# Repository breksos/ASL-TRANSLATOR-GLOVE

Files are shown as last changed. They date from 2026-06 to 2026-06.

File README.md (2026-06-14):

# ASL Sign Language Glove Translator

**GTU CSE496 Graduation Project** — Berk Hakan ÖGE & Utku GÖKÇEK, May–June 2026.

A wearable smart glove that recognises American Sign Language (ASL) gestures
and translates them into spoken text in real time. The user wears the glove,
performs a sign, and a Flutter mobile app speaks the translated word aloud
via TTS.

For the original project brief see [GLOVE_PROJECT.md](GLOVE_PROJECT.md).

---

## Repository layout

```
ASL/
├── README.md                ← you are here
├── GLOVE_PROJECT.md         original brief / spec
│
├── firmware/                ESP32 firmware (sender + receiver + diagnostics)
│   ├── arduino/             Arduino IDE .ino sketches (primary development path)
│   └── idf/                 ESP-IDF projects (parallel alternative; same logic)
│
├── hardware/
│   └── ASL_Glove/           KiCad PCB design for the prototype board
│
├── flutter_app/             Mobile app — BLE receive + TFLite inference + TTS
│
├── scripts/                 Python tooling
│   ├── record.py            primary data-recording UI
│   ├── strip_palm.py        create no-palm variant of dataset
│   └── diagnostics/         link-quality and sensor-health diagnostics
│       ├── sniff.py
│       ├── palm_check.py
│       ├── motion_check.py
│       ├── long_check.py
│       ├── long_csv_check.py
│       ├── soak_30min.py
│       └── inspect.py
│
├── data/                    labelled training samples (with palm channels)
├── data_nopalm/             same samples, palm stripped (45 channels)
│
└── docs/
    ├── datasheets/          part datasheets (MPU6050, ESP32-C3, etc.)
    └── images/              project photos, diagrams
```

---

## System architecture

```
┌─────────────────────────────────────────────────────────────────────┐
│                              The Glove                              │
│                                                                     │
│  ┌────────┐  ┌────────┐  ┌────────┐  ┌────────┐  ┌────────┐         │
│  │ thumb  │  │ index  │  │ middle │  │  ring  │  │ pinky  │         │
│  │ XIAO+  │  │ XIAO+  │  │ XIAO+  │  │ XIAO+  │  │ XIAO+  │         │
│  │ MPU6050│  │ MPU6050│  │ MPU6050│  │ MPU6050│  │ MPU6050│         │
│  └───┬────┘  └───┬────┘  └───┬────┘  └───┬────┘  └───┬────┘         │
│      │ ESP-NOW broadcast, channel 11, 50 Hz, dup-send               │
│      └────────────┬───────────┴───────────┴───────────┘             │
│                   ▼                                                 │
│         ┌────────────────────┐                                      │
│         │  ESP32 DevKit1     │                                      │
│         │  (back of wrist)   │                                      │
│         └─────┬──────────────┘                                      │
└───────────────┼─────────────────────────────────────────────────────┘
                │
                │  USB Serial (CSV) for recording sessions
                │  OR
                │  BLE GATT notify (45 floats × 50 Hz) for phone
                ▼
        ┌───────────────┐               ┌──────────────────────┐
        │   record.py   │               │   Flutter app        │
        │  (laptop)     │               │   (Android phone)    │
        │   → CSV files │               │   TFLite + TTS       │
        └───────┬───────┘               └──────────────────────┘
                ▼
        ┌──────────────────┐
        │  Edge Impulse    │
        │  CNN training    │
        │  → .tflite       │
        └──────────────────┘
                │
                └────────────► flutter_app/assets/models/
```

---

## Quick-start by role

### "I want to flash the firmware"

```sh
# Arduino — primary path
cd firmware/arduino
# Open the project you want in Arduino IDE 2.x (e.g. asl_finger_sender)
# Set FINGER_ID 1..5 per board, flash to each XIAO ESP32-C3
# Flash asl_hand_receiver to the DevKit1
```

Details: see [firmware/arduino/README.md](firmware/arduino/README.md).

For the IDF equivalent: see [firmware/idf/README.md](firmware/idf/README.md).

### "I want to record training data"

```sh
pip install pyserial
python scripts/record.py --port COM15 --label A
```

Press SPACE to record a sample, type a letter to change label, q to quit.
Saves `data/<label>/<label>_NNN.csv`. See `python scripts/record.py --help`.

### "I want to diagnose link health"

```sh
# Quick 20 s per-source rate + max gap
python scripts/diagnostics/palm_check.py

# 30 s while the user signs — checks for motion-induced loss
python scripts/diagnostics/motion_check.py

# 30 min passive soak — checks thermal/firmware stability
python scripts/diagnostics/soak_30min.py

# 5 min CSV-mode soak (asl_csv_logger firmware)
python scripts/diagnostics/long_csv_check.py
```

### "I want to train a model"

1. Record dataset to `data/<label>/*.csv` via `record.py`
2. (Optional) Strip palm channels: `python scripts/strip_palm.py` produces `data_nopalm/`
3. Upload to Edge Impulse with `edge-impulse-uploader --category split --label <X> data/<X>/*.csv` per class
4. Configure impulse: window 2000 ms, stride 500 ms, 50 Hz, **Raw Data**, **Classification (Keras)**
5. Normalize features: **scikit-learn StandardScaler**
6. Use the 1D CNN architecture (see `flutter_app/README.md` for the Keras code)
7. Train, evaluate on Model Testing tab
8. Deployment → TensorFlow Lite → download

### "I want to run the mobile app"

See [flutter_app/README.md](flutter_app/README.md) for full setup. The summary:

1. `cd flutter_app && flutter create --org com.gtu.aslglove --project-name asl_glove .`
2. Drop `asl-letters.tflite`, `asl-words.tflite` + labels into `assets/models/`
3. Drop normalization `stats.json` into `assets/normalization/`
4. `flutter run`

---

## Project status checklist

| Component | Status |
|---|---|
| Sender firmware (Arduino + IDF) | ✅ working, current |
| Receiver firmware (USB CSV path) | ✅ working |
| Receiver firmware (BLE bridge for phone) | ⏳ pending |
| Data recorder (`record.py`) | ✅ working |
| Diagnostic scripts | ✅ working |
| Smoke dataset (5 signs × 30) | ✅ collected |
| Smoke model (1D CNN, no-palm) | ✅ 87.7 % test accuracy |
| Letter dataset (A–Z × 60, multi-session) | ⏳ pending |
| Word dataset (15–20 signs × 60) | ⏳ pending |
| Flutter app skeleton | ✅ written, awaiting model file |
| Trie disambiguation engine | ⏳ pending |

---

## Key engineering decisions

- **Distributed ESP-NOW**, not a wired I2C mux — each finger XIAO transmits independently. Eliminates long wires across joints.
- **Channel 11**, not the default channel 6 — local 2.4 GHz neighbours saturate channel 6.
- **Duplicate-send on every sender** — each packet broadcast twice 800 µs apart. Receiver dedupes by `seq`. Roughly squares the loss rate.
- **External U.FL antennas** instead of the XIAO's PCB chip antenna — measured 10–15× link-loss improvement.
- **Palm MPU dropped** after A/B testing showed identical overall accuracy and *improved* NO class F1 without it. 45-channel input instead of 54.
- **1D CNN architecture**, not the default MLP — boosted test accuracy from 55 % to 88 % on fresh recordings.
- **Mobile-side ML** — ESP32 lacks compute for real-time CNN; phone runs the model.

---

## Open tasks (high-level)

Tracked in detail in the project's task list. Headline items:

1. Reassemble the glove with brick-pattern antenna layout + tight compression glove + clean power distribution
2. Multi-session data collection (4 sessions × 15 samples per sign)
3. Train production Letters and Words models
4. Add BLE GATT server to receiver firmware
5. Implement Trie engine for U/V, M/N, S/T disambiguation in letter mode

---

## License

Academic project, GTU CSE496. Use is permitted for educational reference;
contact authors for commercial use.

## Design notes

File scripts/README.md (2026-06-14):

# Python tooling

Two tiers:

| Tier | Purpose |
|---|---|
| `record.py`, `strip_palm.py` | Primary tools used during normal workflow |
| `diagnostics/*.py` | Link-quality + sensor-health monitors used when something seems off |

All scripts assume:
- Python 3.10+
- `pyserial` installed (`pip install pyserial`)
- Receiver is flashed with `asl_csv_logger` (CSV output, 921 600 baud)
- The repo's `data/` and `data_nopalm/` folders live at the project root

## Primary tools

### `record.py`

```sh
python scripts/record.py --port COM15 --label A
```

Interactive sample recorder. SPACE = record one 3-second window. Type a letter
+ Enter to change label. q = quit. Files land in `data/<label>/<label>_NNN.csv`.

Per-source staleness is checked at end of each window:
- Finger stale > 500 ms → prompt y/n
- Palm stale > 1500 ms → informational note, sample saved

### `strip_palm.py`

```sh
python scripts/strip_palm.py
```

Reads `data/<label>/*.csv` (55 columns: timestamp + 6 sources × 9 fields).
Writes `data_nopalm/<label>/*.csv` (46 columns: timestamp + 5 sources × 9
fields, palm channels removed).

Use after the A/B test verified palm doesn't help accuracy on your data.

## Diagnostics

All take 10-300 seconds; all open COM15 directly (DTR-resets the receiver on
open). Close Arduino Serial Monitor first or they'll fail with a permission
error.

### `diagnostics/sniff.py`

10-second raw capture; writes lines to `_sniff.log` in the project root.
General-purpose "what's actually coming out of the receiver right now".

### `diagnostics/palm_check.py`

20-second per-source health: packet rate, max inter-packet gap, % loss.
Used for "is the link clean right now?"

### `diagnostics/motion_check.py`

30 s test where you wear the glove and perform signs. Reports max gap per
source. Distinguishes static-pose link quality vs motion-induced loss.

### `diagnostics/long_check.py`

5-minute soak using the live-PRY receiver firmware (not CSV).

### `diagnostics/long_csv_check.py`

5-minute soak using the CSV-logger receiver firmware. Per-30-second bucket
packet counts per source. Used to confirm palm survival across a long session.

### `diagnostics/soak_30min.py`

30-minute passive soak (glove on desk, not worn). Identifies thermal /
firmware-state failures distinct from motion-induced RF issues.

### `diagnostics/inspect.py`

```sh
python scripts/diagnostics/inspect.py path/to/data/A
```

Sanity-checks every CSV in a label folder: row count, NaN, all-zero detection,
intra-sample std, across-sample drift. Run after a recording session before
uploading to Edge Impulse.

## Conventions

- All output files (CSVs, logs) go to the project root or `data/` — never to
  `scripts/`.
- COM port is hardcoded to **COM15** in many diagnostics; edit the file or
  pass `--port` where supported.
- No path is relative — they use absolute paths anchored at
  `C:\Users\ASUS\Desktop\Projeler\ASL`. If you move the repo, update them.

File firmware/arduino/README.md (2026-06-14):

# Arduino firmware

Primary firmware tree. Open each project in Arduino IDE 2.x; each subfolder
is one `.ino` sketch that compiles to one board.

## Projects

| Sketch | Target board | Role |
|---|---|---|
| `asl_finger_sender/` | XIAO ESP32-C3 | One per finger. Set `FINGER_ID` 1..5 before flashing each board. |
| `asl_hand_receiver/` | ESP32 DevKit v1 | Receives all 5 fingers via ESP-NOW + local palm IMU. Emits CSV over USB. |
| `asl_csv_logger/` | ESP32 DevKit v1 | Variant of the receiver — pure CSV output at 921 600 baud, no live PRY prints. Used with `scripts/record.py`. |
| `pinky_test/` | XIAO ESP32-C3 | Sender variant that prints diagnostics over USB while still broadcasting. Use to isolate which board is dropping packets. |
| `i2c_scan/` | XIAO ESP32-C3 | Confirms MPU6050 is wired correctly on each finger. |
| `print_mac/` | XIAO ESP32-C3 | Prints the board's STA MAC. Label your boards. |
| `hello_test/` | XIAO ESP32-C3 | Minimal blink/heartbeat sanity check. |

## Flash workflow

1. **Per finger** (5 times, FINGER_ID 1..5):
   - Open `asl_finger_sender/asl_finger_sender.ino`
   - Edit `#define FINGER_ID` near the top to the finger you're flashing
   - Tools → Board → "XIAO_ESP32C3"; Port: pick the right COM
   - Upload, watch the boot log: `[Finger N] starting…`
2. **Receiver**:
   - Open `asl_hand_receiver/asl_hand_receiver.ino` (for normal live use)
   - OR `asl_csv_logger/asl_csv_logger.ino` (for recording sessions)
   - Tools → Board → "ESP32 Dev Module"
   - Upload, open Serial Monitor at **921 600 baud**

## Build settings

| Setting | Value |
|---|---|
| Board family | Arduino-ESP32 core 3.x (Espressif via Boards Manager) |
| Sender CPU freq | default (160 MHz) |
| Receiver CPU freq | default (240 MHz) |
| Partition scheme | default |

## Hardware assumptions (latest)

- ESP-NOW channel: **11** (not the default 6 — channel 6 is RF-congested in the lab)
- Senders broadcast in dup-send mode (each packet twice with 800 µs gap)
- Phase stagger: 4 ms × (FINGER_ID − 1)
- I2C: SDA = GPIO 6, SCL = GPIO 7 on XIAO; SDA = GPIO 21, SCL = GPIO 22 on DevKit1
- Receiver palm: optional (removed in current production design, code still supports it)
- All boards run on a shared 5 V rail from a 5 A bench adapter
- DevKit1 receiver: mounted on back of wrist, antenna end (meander trace) pointing toward fingertips

## Related Python tooling

| Tool | What |
|---|---|
| `scripts/record.py` | Drives `asl_csv_logger` over USB, captures labelled samples |
| `scripts/diagnostics/*` | Link-quality + sensor-health monitors that consume the receiver's USB output |

## See also

- `firmware/idf/README.md` for the ESP-IDF equivalent
- Top-level `README.md` for the system architecture overview

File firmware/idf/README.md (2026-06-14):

# ASL Glove — ESP-IDF version

Ported from the Arduino `.ino` sketches in `ASL_Latest_Ver/` and rewritten with
every fix from the precision/noise review. One PlatformIO-style project per
firmware image; shared MPU6050 + Kalman code lives in `components/glove_common`.

## Requirements

- **ESP-IDF v5.4 or newer** (uses the new `i2c_master` driver and the
  `wifi_tx_info_t` ESP-NOW send-callback signature).
- Python 3.8+, the `esptool`/`idf.py` toolchain (installed by ESP-IDF).
- VS Code with the official **Espressif IDF** extension is the easiest way to
  build/flash from a GUI; everything also works from the IDF shell.

## Projects

| Folder | Target | Role |
|---|---|---|
| `asl_finger_sender` | esp32c3 | One image per finger XIAO. Edit `FINGER_ID` (1..5) in `main/main.c` before each flash. |
| `asl_hand_receiver` | esp32 | DevKit1 on back of hand. Reads palm IMU locally + receives fingers over ESP-NOW. Live PRY @ 5 Hz, stats @ 1 Hz. |
| `asl_csv_logger` | esp32 | Same wiring as receiver, but emits one CSV row per packet on UART @ 921600 baud. Use for data-loss analysis. |
| `pinky_test` | esp32c3 | Pinky XIAO with extra USB diagnostics every 5 s (I2C ok/fail, max consecutive failure burst, send ok/fail). Behaves as `FINGER_ID=5` for the rest of the glove. |
| `i2c_scan` | esp32c3 | Probes every 7-bit I2C address — sanity check the MPU6050 wiring on a XIAO. |
| `print_mac` | esp32c3 | Prints STA MAC, used to label modules. |

## Build / flash workflow

From the IDF shell (or VS Code → "ESP-IDF: Open ESP-IDF Terminal"):

```sh
cd IDF_Ver/asl_finger_sender
idf.py set-target esp32c3           # only first time, or after changing target
idf.py build
idf.py -p COM7 flash monitor        # adjust COM port
```

Stop the monitor with `Ctrl+]`.

The receiver and CSV logger use `esp32` target:
```sh
cd IDF_Ver/asl_hand_receiver
idf.py set-target esp32
idf.py build
idf.py -p COM15 flash monitor
```

### Per-finger flashing
`FINGER_ID` is a `#define` in `asl_finger_sender/main/main.c`. Change it,
rebuild, flash. Recommended workflow: tape a label with the finger name on
each XIAO before mounting, and keep a list of which MAC → finger so you can
re-flash later without confusion (`print_mac` helps here).

### ESP-NOW channel
All boards must agree on `ESPNOW_CHANNEL` — defined in `asl_finger_sender`,
`pinky_test`, `asl_hand_receiver`, `asl_csv_logger`. Default is 6. If your
home Wi-Fi router is on channel 6 you will see packet loss in the receiver
`[stats]` output; change to 1 or 11 on every board.

## What the optimised firmware does differently

The review went through each issue; this is a compressed map from "fix" to
"where it lives" so you can audit the code.

| Fix from review | Implementation |
|---|---|
| Accel-magnitude gating in Kalman | `if (dev_g < ACCEL_GATE_MS2) kalman_update(...) else kalman_predict(...)` in every sampling loop |
| DLPF 10 Hz (was 21 Hz) | `wreg(m, REG_CONFIG, 0x05)` in [mpu6050.c](components/glove_common/mpu6050.c) |
| I2C @ 400 kHz (was 100 kHz) | `scl_speed_hz = 400000` in `mpu6050.c::open_bus` |
| Deadline scheduler (was `delay(20)`) | `next_us += PERIOD_US; spin until esp_timer_get_time() >= next_us` |
| `dt` fallback fixed | `dt = SEND_PERIOD_US / 1e6f` (was a wrong 0.01s default) |
| Calibration stillness check | `mpu6050_calibrate_still()` computes gyro variance and rejects if it exceeds 4 dps² |
| Average raw accel, not angles | `mpu6050_calibrate_still()` sums `ax,ay,az` then calls `atan2` once |
| Online gyro-bias EMA when still | `cal.gx_bias += BIAS_EMA_ALPHA * (g[0] - cal.gx_bias)` in every loop |
| Yaw reset on sustained stillness | `if (still_since > 0 && (now - still_since) > STILL_RESET_US) yaw = 0` — replaces the old `yaw *= 0.99` |
| Serial @ 921 600 on receivers | `CONFIG_ESP_CONSOLE_UART_BAUDRATE=921600` in `sdkconfig.defaults` |
| Receiver live print slowed to 5 Hz | `last_print > 200 ms` in `asl_hand_receiver` |
| Palm IMU in its own FreeRTOS task | `xTaskCreate(palm_task, ...)` in receiver / CSV logger |
| CSV emit out of ESP-NOW callback | `xQueueSend` from `recv_cb`, `emitter_task` drains and prints |
| Reset-tolerant loss counter | `else if (p.seq < s->seq) { s->lost_count = 0; }` in receiver `recv_cb` |
| TX failure counter on all senders | `s_tx_ok / s_tx_fail_cb / s_tx_fail_imm` in every sender |
| I2C bus recovery | `mpu6050_recover_bus()` — bit-bangs SCL 9 times and reinits the bus |

## Repository layout
```
IDF_Ver/
├── README.md                       ← this file
├── components/
│   └── glove_common/
│       ├── CMakeLists.txt
│       ├── include/
│       │   ├── kalman.h
│       │   ├── mpu6050.h
│       │   └── packet.h
│       ├── kalman.c
│       └── mpu6050.c
├── asl_finger_sender/  …
├── asl_hand_receiver/  …
├── asl_csv_logger/     …
├── pinky_test/         …
├── i2c_scan/           …
└── print_mac/          …
```

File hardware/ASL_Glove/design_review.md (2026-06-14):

# ASL Glove Design Review

**Project:** ASL_Glove (KiCad 9, single sheet, 2-layer PCB)
**Date:** 2026-04-03
**Analyzers:** analyze_schematic.py, analyze_pcb.py (--full), analyze_emc.py
**Datasheets:** MPU-6050.pdf (104KB, InvenSense), ESP32-C3_datasheet.pdf (875KB, Espressif)

---

## Critical Findings

| Severity | Issue | Section |
|---|---|---|
| WARNING | CPOUT (MPU-6050 pin 20) has no decoupling capacitor — IMU may not function | Signal Analysis |
| WARNING | GND copper pour zone is defined but NOT filled — no ground plane on board | PCB Layout |
| WARNING | Power traces (+3V3, GND) use 0.2mm width — marginal for ESP32-C3 peak Wi-Fi current | PCB Layout |
| WARNING | No MPNs on any component (0% MPN coverage) — board cannot be ordered without manual lookup | Component Summary |
| SUGGESTION | All signal nets are unnamed — I2C, UART, and config signals have auto-generated names | Schematic Quality |
| SUGGESTION | Missing bulk cap (10µF) near MPU-6050 VDD — datasheet recommends 100nF + 10µF | Signal Analysis |

---

## Component Summary

| Type | Count | References |
|---|---|---|
| IC / Module | 2 | U1 (ESP32-C3-DevKitM-1), U2 (MPU-6050) |
| Capacitor | 4 | C1–C4 |
| Resistor | 3 | R1–R3 |
| Connector | 1 | J1 (Conn_01x02) |
| Jumper | 1 | JP1 (ROLE_SEL) |
| Test point | 4 | TP1–TP4 (TX, RX, GND, 3V3) |
| **Total** | **15** | |

**Nets:** 36 schematic / 37 PCB | **No-connects:** 18 | **Power rails:** +3V3, GND

**Sourcing audit:** 0/10 components have MPNs. All parts require manual MPN assignment before ordering or JLCPCB assembly.

---

## Power Tree

```
J1 (external 3.3V supply)
  └── +3V3 rail ─── U1 3V3 pin (bidirectional — also sources from USB LDO on DevKitM-1)
                ├── U2 VDD (pin 13)
                ├── U2 VLOGIC (pin 8)
                ├── C1 100nF (bulk decoupling)
                ├── C2 10µF  (bulk decoupling)
                ├── C3 100nF (MPU-6050 VDD decoupling)
                ├── C4 100nF (MPU-6050 VDD decoupling)
                ├── R1 4.7kΩ (I2C SDA pull-up)
                ├── R2 4.7kΩ (I2C SCL pull-up)
                └── R3 10kΩ  (JP1 ROLE_SEL pull-up)
```

**Note:** The ESP32-C3-DevKitM-1 module has its own onboard 3.3V LDO from USB VBUS. When the board is powered via USB, U1's 3V3 pins source +3V3. When powered externally via J1, J1 drives the +3V3 rail. Both paths connect to the same rail — avoid powering both simultaneously unless a diode-OR circuit is used.

---

## Analyzer Verification

### Component Count
Schematic: 15 components (excluding power symbols) — PCB: 15 footprints. **Match ✓**

### Component Pinout Verification

| Ref | Value | Datasheet Verified | Key Connections | Status |
|-----|---|---|---|---|
| U1 | ESP32-C3-DevKitM-1 | Unverified (PDF unavailable — web page URL only) | GND(1), 3V3(2,3), IO10(11), IO8/SDA(25), IO9/SCL(26), RX(28), TX(29) | Plausible — standard DevKitM-1 pinout |
| U2 | MPU-6050 | Unverified (pdftoppm unavailable) | VDD(13)=3V3, VLOGIC(8)=3V3, GND(18), AD0(9)=GND, FSYNC(11)=GND, SCL(23), SDA(24) | Plausible — matches standard MPU-6050 symbol |
| R1 | 4.7kΩ | Skipped (2-pin passive) | Pin1=3V3, Pin2=SDA | ✓ |
| R2 | 4.7kΩ | Skipped (2-pin passive) | Pin1=3V3, Pin2=SCL | ✓ |
| R3 | 10kΩ | Skipped (2-pin passive) | Pin1=3V3, Pin2=JP1/IO10 | ✓ |
| C1–C4 | 100nF/10µF | Skipped (2-pin passive) | +3V3/GND | ✓ |
| J1 | Conn_01x02 | Skipped | Pin1=+3V3, Pin2=GND | ✓ |
| JP1 | ROLE_SEL | Skipped | Pin1=IO10 via R3, Pin2=GND | ✓ |

**Verification gap:** pdftoppm is not available in this environment, so datasheet PDFs could not be read directly. The MPU-6050 pinout is based on well-known community knowledge of this part (extremely common, stable for 15+ years). U1 pinout is based on the KiCad symbol for the DevKitM-1 dev board module. Both are assessed as **plausible** — but formal datasheet verification is recommended before ordering.

### Connector Pin Tables

**J1 (Power input):**
| Pin | Net | Function |
|-----|-----|---|
| 1 | +3V3 | 3.3V supply input |
| 2 | GND | Ground |

**JP1 (ROLE_SEL jumper):**
| Pin | Net | Function |
|-----|-----|---|
| 1 | IO10 (via R3 10kΩ to +3V3) | Role select signal — HIGH when open, LOW when shorted to GND |
| 2 | GND | Ground |

**Test points:**
| Ref | Net | Label |
|-----|-----|---|
| TP1 | U1.TX | UART TX |
| TP2 | U1.RX | UART RX |
| TP3 | GND | Ground |
| TP4 | +3V3 | 3.3V supply |

### Net Tracing

**+3V3 power rail:** J1.1 → U1.2/3 → U2.VDD(13) → U2.VLOGIC(8) → C1/C2/C3/C4 → R1.1 → R2.1 → R3.1 → TP4. Continuous, no gaps. ✓

**GND:** J1.2 → U1.GND(1,6,8,12,15,16,19,24,27,30) → U2.GND(18) → U2.AD0(9) → U2.FSYNC(11) → C1/C2/C3/C4 → JP1.2 → TP3. Continuous. ✓

**I2C SDA:** R1.2 → U2.SDA(24) → U1.IO8(25). ✓

**I2C SCL:** R2.2 → U2.SCL(23) → U1.IO9(26). ✓

**UART TX:** U1.TX(29) → TP1. ✓

**UART RX:** U1.RX(28) → TP2. ✓

**ROLE_SEL:** +3V3 → R3(10kΩ) → U1.IO10(11) → JP1.1 (and JP1.2=GND). When JP1 open: IO10 pulled HIGH. When shorted: IO10 pulled LOW. ✓

### PCB Verification

- Footprint count: 15 schematic = 15 PCB ✓
- Board dimensions: 32.0 × 34.0mm
- Routing: complete (0 unrouted nets)
- Vias: **0** (no vias at all)

---

## Signal Analysis Review

### I2C Bus

Detected correctly: ESP32-C3 (master) ↔ MPU-6050 (slave, AD0=GND → address 0x68).

| Parameter | Value | Assessment |
|---|---|---|
| SDA pull-up | R1 = 4.7kΩ to +3V3 | ✓ Standard — appropriate for 100/400kHz I2C |
| SCL pull-up | R2 = 4.7kΩ to +3V3 | ✓ Standard |
| Bus capacitance (estimated) | ~10pF | Low (2 devices, short traces) — rise time well within spec |
| I2C address | 0x68 (AD0=GND) | ✓ |

**I2C GPIO assignment:** IO8 (SDA) and IO9 (SCL). On ESP32-C3, I2C can be mapped to any GPIO via the `i2c_param_config()` driver call. Both GPIO8 and GPIO9 are valid for I2C — no issues.

### MPU-6050 Application Circuit

The MPU-6050 requires specific external components beyond VDD/GND decoupling:

| Requirement | Schematic | Status |
|---|---|---|
| VDD decoupling 100nF | C3 or C4 (100nF, ~5mm) | ✓ Present |
| VDD bulk cap 10µF | Not present | **WARNING** — datasheet recommends 100nF + 10µF |
| VLOGIC decoupling 100nF | C3/C4 shared rail | Acceptable (VLOGIC=VDD=3.3V here) |
| CPOUT cap 2.2nF to GND | **Not present** | **WARNING — required for internal charge pump** |
| REGOUT cap 100nF | NC (pin 20 floats) | **WARNING** — floated; should have cap to GND |

The CPOUT / REGOUT omission is the highest-risk issue in this design. Without the charge pump capacitor, the MPU-6050's internal oscillator may not start reliably, resulting in no IMU data.

### Decoupling Coverage

| IC | Closest Cap | Distance | Assessment |
|----|---|---|---|
| U1 (ESP32-C3-DevKitM-1) | C1 (100nF) + C2 (10µF) | 9.06mm | Module has onboard decoupling — external caps serve as rail bulk supply. Acceptable for a dev board module. |
| U2 (MPU-6050) | C4 (100nF) | 4.94mm | Borderline — under 5mm is acceptable but closer is better. Missing 10µF bulk. |

### Protection Devices

No ESD or TVS protection on any connector. J1 (power input) and JP1 (external header) are exposed interfaces with no protection. For a glove device that will be plugged/unplugged in the field, TVS protection on J1 is recommended.

---

## PCB Layout Review

### Ground Plane — CRITICAL GAP

The GND zone is **defined** in the PCB but **not filled** (`is_filled: false`). There is no copper pour on either layer for GND. This has significant consequences:

1. **EMC**: Return currents take longer paths through traces instead of a solid plane — increases radiated emissions
2. **Signal integrity**: I2C and UART signals lack controlled return paths
3. **Noise**: MPU-6050 is sensitive to power supply noise; a ground plane significantly reduces it

**Fix:** In KiCad, press `B` (Edit → Fill All Zones) before generating Gerbers. The zone outline is already drawn.

### Power Trace Width

| Net | Current trace width | Est. peak current | IPC-2221 minimum (1oz, external) | Status |
|-----|---|---|---|---|
| +3V3 | 0.2mm | ~150mA (ESP32 Wi-Fi peak) | ~0.3mm for 150mA, 10°C rise | Marginal |
| GND | 0.2mm | ~150mA | ~0.3mm | Marginal |

The ESP32-C3 module draws up to ~150mA peak during Wi-Fi TX bursts. The current 0.2mm traces are at the minimum DRC rule limit and within acceptable range for average current (the module's onboard LDO handles instantaneous peaks), but widening to 0.5mm would reduce voltage droop and improve reliability.

### Via Stitching

**0 vias on the entire board.** Since all components are on F.Cu and there's no B.Cu routing, vias are not needed for signal routing. However, ground stitching vias connecting the GND zone (once filled) to a B.Cu GND pour would significantly improve EMC. See EMC findings.

### Placement

| Issue | Detail |
|---|---|
| J1 edge clearance | 0.7mm — passes DRC (0.5mm minimum), but tight for a connector |
| Component density | 1.4 components/cm² — moderate density, no courtyard overlaps |
| All components front side | ✓ — simplifies assembly |

### DFM (JLCPCB Standard Tier)

| Metric | Value | Limit | Status |
|---|---|---|---|
| Min track width | 0.2mm | 0.127mm | ✓ |
| Min spacing | 0.3mm | 0.127mm | ✓ |
| Board size | 32×34mm | Up to 500×500mm | ✓ |
| DRC violations | 0 | 0 | ✓ |

---

## EMC Summary (from analyze_emc.py)

**Score: 87/100** — see `emc_analysis.json` for full findings. Key items:

| Severity | Rule | Finding |
|---|---|---|
| HIGH | DC-001 | Decoupling caps 9.1mm from U1 — acceptable for module, monitor if noise issues |
| MEDIUM | VS-001 | No ground stitching vias |
| LOW | IO-001 | No filtering on J1 or JP1 connectors |
| INFO | EE-001 | Board resonance at 2102/2233 MHz — near 2.4GHz Wi-Fi band |

---

## Issues Found — Prioritized

| Priority | Severity | Issue | Fix |
|---|---|---|-----|
| 1 | WARNING | MPU-6050 CPOUT/REGOUT has no capacitor — IMU may not work | Add 2.2nF to CPOUT (pin 20) and 100nF to REGOUT (pin 10), both to GND |
| 2 | WARNING | GND copper pour not filled | Press `B` in KiCad PCB editor before exporting Gerbers |
| 3 | WARNING | Power traces only 0.2mm | Widen +3V3 and GND traces to 0.5mm |
| 4 | WARNING | 0% MPN coverage | Add MPN properties to all components; especially U1, U2 |
| 5 | SUGGESTION | Missing bulk cap near MPU-6050 | Add 10µF capacitor near U2 VDD |
| 6 | SUGGESTION | All signal nets unnamed | Add net labels: SDA, SCL, TX, RX, ROLE_SEL |
| 7 | SUGGESTION | No ESD protection on J1 | Add TVS (e.g., PRTR5V0U2X) on J1 power pins |
| 8 | SUGGESTION | GND PWR_FLAG missing | Add PWR_FLAG to GND net to suppress ERC warning |
| 9 | SUGGESTION | No ground stitching vias | Add stitching vias around board edges after filling GND zone |

---

## Positive Findings

- Routing is complete — no unrouted nets
- I2C pull-up values (4.7kΩ) are correct for 3.3V bus at 100/400kHz
- MPU-6050 I2C address (AD0=GND → 0x68) is explicitly set
- FSYNC tied to GND — correct for standalone IMU operation
- Test points provided for UART TX/RX, GND, and 3V3 — good for debug
- DFM passes JLCPCB standard tier — manufacturable as-is
- ROLE_SEL jumper has proper pull-up — clean logic level configuration

---

## Generated Files

| File | Purpose | Regenerable |
|---|---|---|
| `schematic_analysis.json` | Schematic analyzer output | Yes |
| `pcb_analysis.json` | PCB analyzer output (--full) | Yes |
| `emc_analysis.json` | EMC pre-compliance analysis | Yes |
| `datasheets/MPU-6050.pdf` | InvenSense MPU-6050 datasheet | Yes |
| `datasheets/ESP32-C3_datasheet.pdf` | Espressif ESP32-C3 datasheet | Yes |
| `datasheets/index.json` | Datasheet manifest | Yes |
| `design_review.md` | This report | Yes |

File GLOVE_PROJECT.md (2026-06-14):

# ASL Sign Language Glove Translator — Project Brief
**GTU CSE496 Graduation Project | Berk Hakan ÖGE & Utku GÖKÇEK**

---

## What This Project Does
A wearable smart glove that recognizes American Sign Language (ASL) gestures and translates them into spoken text in real time. The user wears the glove, performs a sign, and a companion Flutter mobile app speaks the translated word aloud via TTS.

**Two-layer recognition:**
1. **Word-level gestures** — ~30–50 common ASL signs (hello, yes, no, help, water, etc.) using dynamic IMU motion over time
2. **Fingerspelling fallback** — A–Z static letters for names and unknown words, with context-aware disambiguation (trie-based word completion) for ambiguous letter pairs (U/V, M/N, S/T)

---

## Hardware (All Parts In Hand)

### On the Glove
| Component | Qty | Role |
|---|---|---|
| ESP32 DevKit V1 | 1 | Main MCU — reads all sensors, streams raw data over BLE |
| MPU6050 GY-521 | 6 | 6-axis IMU — 5 on fingers (one per finger) + 1 on back of hand for wrist/global orientation |
| TCA9548A I2C Multiplexer | 1 | Lets all 6 MPU6050s (same I2C address 0x68) coexist on one ESP32 I2C bus |
| Flex Sensor 2.2" | 5 | Analog bend detection per finger — supplements IMU data for stronger dataset |
| CD4051 Analog Multiplexer | 1 | Routes all 5 flex sensor ADC signals into single ESP32 ADC pin |
| Li-Po 3.7V 1000mAh | 1 | Power source |
| TP4056 USB-C charger | 1 | Safe Li-Po charging |

### Mobile
| Component | Role |
|---|---|
| Flutter App (Android/iOS) | BLE receive → ML classification → text buffer → TTS output |

---

## Architecture

```
[Glove Hardware]
  5x Flex Sensors
       │
    CD4051 (analog mux)
       │ (1 ADC pin)
       ▼
  ESP32 DevKit V1  ◄──── 6x MPU6050
       │                     │
       │              TCA9548A (I2C mux)
       │              GPIO21=SDA, GPIO22=SCL
       │
    [BLE]
       │
       ▼
  Flutter Mobile App
       │
   ┌───┴────────────┐
   │  ML Model      │  ← 1D CNN (TFLite) trained via Edge Impulse
   │  Text Buffer   │  ← accumulates letters/words
   │  Trie Engine   │  ← context disambiguation for ambiguous letters
   │  TTS Output    │  ← flutter_tts
   └────────────────┘
```

**Key architectural decisions:**
- ML runs on **mobile, not ESP32** — ESP32 is too weak for real-time model inference
- ESP32 only streams **raw sensor data** over BLE — no classification on device
- TCA9548A eliminates need for a second ESP32 — single board handles all 6 IMUs
- CD4051 is on a **separate analog bus** from TCA9548A — no conflict

---

## ESP32 Pin Mapping

| Pin | Function |
|---|---|
| GPIO21 | I2C SDA → TCA9548A |
| GPIO22 | I2C SCL → TCA9548A |
| GPIO34 (ADC) | CD4051 output (flex sensors) |
| GPIO25 | CD4051 select pin A |
| GPIO26 | CD4051 select pin B |
| GPIO27 | CD4051 select pin C |
| Built-in radio | BLE (no extra pins needed) |

**TCA9548A channels:**
- Channel 0 → MPU6050 (thumb)
- Channel 1 → MPU6050 (index finger)
- Channel 2 → MPU6050 (middle finger)
- Channel 3 → MPU6050 (ring finger)
- Channel 4 → MPU6050 (pinky finger)
- Channel 5 → MPU6050 (back of hand / wrist)
- Channels 6–7 → spare

**CD4051 channels:**
- Channel 0 → Flex sensor (thumb)
- Channel 1 → Flex sensor (index)
- Channel 2 → Flex sensor (middle)
- Channel 3 → Flex sensor (ring)
- Channel 4 → Flex sensor (pinky)

---

## Sensor Data Format

Each sample is a time window of raw readings streamed from ESP32 to mobile over BLE.

**Per timestamp (at 50Hz):**
```
imu[0..5]: { accelX, accelY, accelZ, gyroX, gyroY, gyroZ }  // 6 IMUs × 6 values = 36
flex[0..4]: { raw_adc }                                        // 5 flex values
─────────────────────────────────────────────────────────────
Total per sample: 41 values
At 50Hz over 1s window: 50 × 41 = 2050 values per gesture
```

BLE packet: send as packed float array or JSON — keep under BLE MTU (512 bytes typical). Consider sending at 50Hz as continuous stream and letting mobile handle windowing.

---

## ML Pipeline

### Phase 1 — DTW Baseline (build first, fast to implement)
- Record 1 template per gesture
- At runtime compare live window to all templates using DTW distance
- Classify as closest match
- No training needed — add new gesture by recording one sample
- Use this to validate the full hardware → mobile pipeline works

### Phase 2 — 1D CNN via Edge Impulse (final model)
- Collect 50–100 samples per gesture in Edge Impulse data collector
- Input: time-series window (50 samples × 41 channels)
- Architecture: 1D Conv → Pool → 1D Conv → Pool → Dense → Softmax
- Export as TFLite → integrate into Flutter via `tflite_flutter` package
- Target accuracy: ≥85% letters, ≥90% words

### Gesture vocabulary plan
- **Static letters:** A–Z (fingerspelling)
- **Word gestures (dynamic):** ~30–50 common signs — hello, yes, no, help, water, food, please, sorry, good, bad, I, you, want, need, more, stop, go, thank you, where, what, name, again, understand, know, not, like, want, hurt, sick, call
- **Control gestures:** space (closed fist hold), backspace, switch mode (fingerspell ↔ word)

---

## Flutter App Structure

```
lib/
├── main.dart
├── ble/
│   ├── ble_manager.dart          # flutter_blue_plus — scan, connect, subscribe
│   └── sensor_packet.dart        # parse raw BLE bytes into SensorFrame struct
├── ml/
│   ├── classifier.dart           # load TFLite model, run inference on window
│   ├── dtw_classifier.dart       # DTW baseline (Phase 1)
│   └── gesture_window.dart       # sliding window buffer (1s at 50Hz)
├── text/
│   ├── text_buffer.dart          # accumulate letters → words → sentences
│   ├── trie_engine.dart          # context disambiguation for ambiguous letters
│   └── word_completer.dart       # suggests completions from trie
├── tts/
│   └── tts_manager.dart          # flutter_tts wrapper
└── ui/
    ├── home_screen.dart           # main display — current word, sentence, mode
    └── settings_screen.dart       # BLE device picker, model settings
```

**Flutter dependencies to add:**
```yaml
dependencies:
  flutter_blue_plus: ^1.31.0
  tflite_flutter: ^0.10.4
  flutter_tts: ^3.8.5
  permission_handler: ^11.0.0
```

---

## ESP32 Firmware Structure

```
firmware/
├── src/
│   └── main.cpp
├── lib/
│   ├── TCA9548A/
│   │   └── mux.h              # selectChannel(uint8_t ch), readMPU(uint8_t ch)
│   ├── MPU6050/
│   │   └── imu.h              # initIMU(), readIMU() → struct IMUData
│   ├── FlexSensors/
│   │   └── flex.h             # selectFlex(uint8_t ch), readFlex() → int
│   └── BLE/
│       └── ble_stream.h       # init BLE, sendPacket(float* data, int len)
└── platformio.ini
```

**Key firmware logic:**
```cpp
// Main loop at 50Hz
void loop() {
  for (int ch = 0; ch < 6; ch++) {
    selectMPU(ch);           // TCA9548A switch
    readMPU6050(ch);         // fill imu_data[ch]
  }
  for (int ch = 0; ch < 5; ch++) {
    selectFlex(ch);          // CD4051 switch
    flex_data[ch] = analogRead(ADC_PIN);
  }
  packAndSend();             // BLE notify
  delay(20);                 // 50Hz
}
```

---

## Build Order (Phase by Phase)

### Phase 1 — Hardware Validation (do first)
1. Wire TCA9548A to ESP32 (SDA/SCL)
2. Connect one MPU6050 to TCA9548A channel 0, verify I2C reads
3. Add remaining 5 MPU6050s one at a time, verify each channel
4. Wire CD4051 to ESP32 ADC pin
5. Connect flex sensors through CD4051, verify analog reads
6. Confirm all 11 sensors reading simultaneously at 50Hz via Serial Monitor

### Phase 2 — BLE Streaming
1. Add BLE GATT server to firmware
2. Pack sensor frame as byte array, send via BLE notify characteristic
3. Build minimal Flutter app that connects and prints received packets to console
4. Verify data integrity and latency end-to-end

### Phase 3 — DTW Baseline Classifier
1. Add data logging mode to firmware (dump to Serial as CSV)
2. Record 5–10 gesture templates per sign
3. Implement DTW in Flutter/Dart
4. Test full pipeline: gesture → BLE → classify → display text

### Phase 4 — Dataset Collection + Edge Impulse
1. Set up Edge Impulse project with 41-channel time-series input
2. Collect 50–100 samples per gesture class
3. Train 1D CNN, validate accuracy
4. Export TFLite model
5. Integrate into Flutter via tflite_flutter

### Phase 5 — App Polish
1. Text buffer + trie disambiguation engine
2. TTS output via flutter_tts
3. Word/letter mode switching
4. UI for sentence display

---

## Success Criteria (for TA)
1. Static letter recognition accuracy ≥ 85% across A–Z
2. Word-level gesture accuracy ≥ 90% for defined 30-word vocabulary
3. End-to-end latency (gesture → audio) ≤ 1 second
4. BLE connection stable within 5 seconds of app launch
5. Battery life ≥ 3 hours continuous use

---

## Key Libraries & Tools
| Tool | Purpose |
|---|---|
| PlatformIO | ESP32 firmware development |
| Wire.h | I2C communication (Arduino) |
| MPU6050.h | IMU driver |
| BLEDevice.h | ESP32 BLE server |
| Edge Impulse | Dataset collection + 1D CNN training |
| flutter_blue_plus | BLE client in Flutter |
| tflite_flutter | Run TFLite model in Flutter |
| flutter_tts | Text-to-speech output |

---

## Notes for Claude Code
- Start with Phase 1 hardware validation firmware — get all sensors reading before writing any ML code
- Use PlatformIO, not Arduino IDE — better dependency management
- ESP32 I2C default pins: SDA=GPIO21, SCL=GPIO22
- TCA9548A I2C address: 0x70
- MPU6050 I2C address: 0x68 (all 6 — TCA9548A isolates them)
- CD4051 select pins are digital output (A, B, C = 3-bit binary channel select)
- ADC pin for flex sensors: use GPIO34 (input only, good for ADC)
- BLE MTU on ESP32: negotiate to 512 bytes, send packet every 20ms
- Keep firmware loop simple — no classification logic on ESP32
- All ML, windowing, and text logic lives in Flutter

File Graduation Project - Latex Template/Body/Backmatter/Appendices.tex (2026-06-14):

\chapter*{Appendices}
\addcontentsline{toc}{chapter}{Appendices}

\section*{Appendix 1: Channel Layout of the Feature Vector}

Each 25\,Hz sample is a 45-channel vector in finger-major order. For each finger
in the order thumb, index, middle, ring, pinky, the nine fields are: pitch (P),
roll (R), yaw (Y), angular rate about $x$/$y$/$z$ ($g_x,g_y,g_z$), and linear
acceleration along $x$/$y$/$z$ ($a_x,a_y,a_z$). This ordering is identical in
the data-collection script, the master firmware payload, the normalisation
statistics, and the mobile application's parser.

\section*{Appendix 2: Vocabulary}

\textbf{Letters:} the 26 letters A--Z. Most are encoded as short, distinctive
finger motions; J and Z are the inherently dynamic ASL letters.

\textbf{Words (19 one-handed signs):} DRINK, EAT, FINE, HELLO, HOWAREYOU,
ILOVEYOU, ME, NAME, NO, PLEASE, SORRY, STOP, THANKYOU, WATER, WHAT, WHERE, YES,
YOU, YOUR. The compact multi-word tokens (e.g.\ HOWAREYOU, ILOVEYOU) are
expanded to spaced phrases (``HOW ARE YOU'', ``I LOVE YOU'') for display and
speech in the application.

\section*{Appendix 3: Key System Parameters}

\begin{tabular}{ll}
\toprule
Parameter & Value \\
\midrule
Fingers / channels        & 5 / 45 \\
Sampling rate             & 25\,Hz \\
Capture window            & 3\,s (75 time steps) \\
ESP-NOW channel           & 11 \\
BLE MTU (negotiated)      & 256 bytes \\
BLE payload               & 180 bytes (45 float32) \\
Master CSV baud rate      & 921600 \\
Model quantisation        & int8 (input and output) \\
\bottomrule
\end{tabular}

\section*{Appendix 4: Source Code}

The firmware, data-processing scripts, and mobile application are organised in
the project repository under \texttt{firmware/}, \texttt{scripts/}, and
\texttt{flutter\_app/} respectively.

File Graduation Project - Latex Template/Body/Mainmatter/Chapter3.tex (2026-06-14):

\chapter{System Overview and Hardware Architecture}

\section{Requirements}

From the objectives in Chapter~1, the hardware must (i) sense all five fingers,
(ii) transmit their data to a phone without a wired tether, (iii) be small and
light enough to wear, and (iv) be buildable from affordable, available parts.
These requirements drove the choice of one IMU per finger, an ESP32-class
microcontroller per finger for local processing and radio, and a phone as the
inference and output device.

\section{Component Selection}

Each finger module pairs a \textbf{Seeed Studio XIAO ESP32-C3} \cite{xiao} with
an \textbf{InvenSense MPU6050} \cite{mpu6050}. The XIAO ESP32-C3 was chosen for
its very small footprint, its integrated Wi-Fi/BLE radio (enabling both ESP-NOW
and BLE), its USB-C interface for flashing and power, and its low cost. The
MPU6050 provides the six axes of inertial data over I\textsuperscript{2}C and is
likewise inexpensive and well documented. The phone runs a cross-platform
Flutter application, so no platform-specific hardware is required on the output
side.

\section{The Finger Module}

A finger module is a compact stack: the XIAO and the MPU6050 are soldered
together with very short wires and separated by an insulating pad that also
limits heat transfer from the microcontroller to the sensor; a second
heat-spreading pad sits on top of the microcontroller and is left exposed to
open air so it can actually dissipate heat rather than trap it. The complete
stack mounts on the back of the fingertip (over the nail). Mounting on the
nail—rather than along the finger segments—keeps the sensor on a rigid part of
the finger, simplifies the wiring, and avoids fitting electronics into the
knuckle gaps. Figure~\ref{fig:module} shows a single assembled module.

The I\textsuperscript{2}C bus uses pins D4 (GPIO6, SDA) and D5 (GPIO7, SCL) on
the XIAO at 400\,kHz. Each MPU6050 is configured with a digital low-pass filter
at 10\,Hz, a gyroscope full-scale range of $\pm$500\,$^{\circ}$/s, and an
accelerometer range of $\pm$4\,g.

Five such modules make up the complete device. Figure~\ref{fig:glove} shows the
glove as worn: one module over each fingernail, with the middle-finger module
acting as the master and the remaining four as slaves. All five share a common
power rail, and only the master carries the Bluetooth link to the phone, so the
wiring the user sees is deliberately minimal—short inter-module runs and a
single cable to the power source.

% FIGURE — single finger module.
\begin{figure}[!htbp]
    \centering
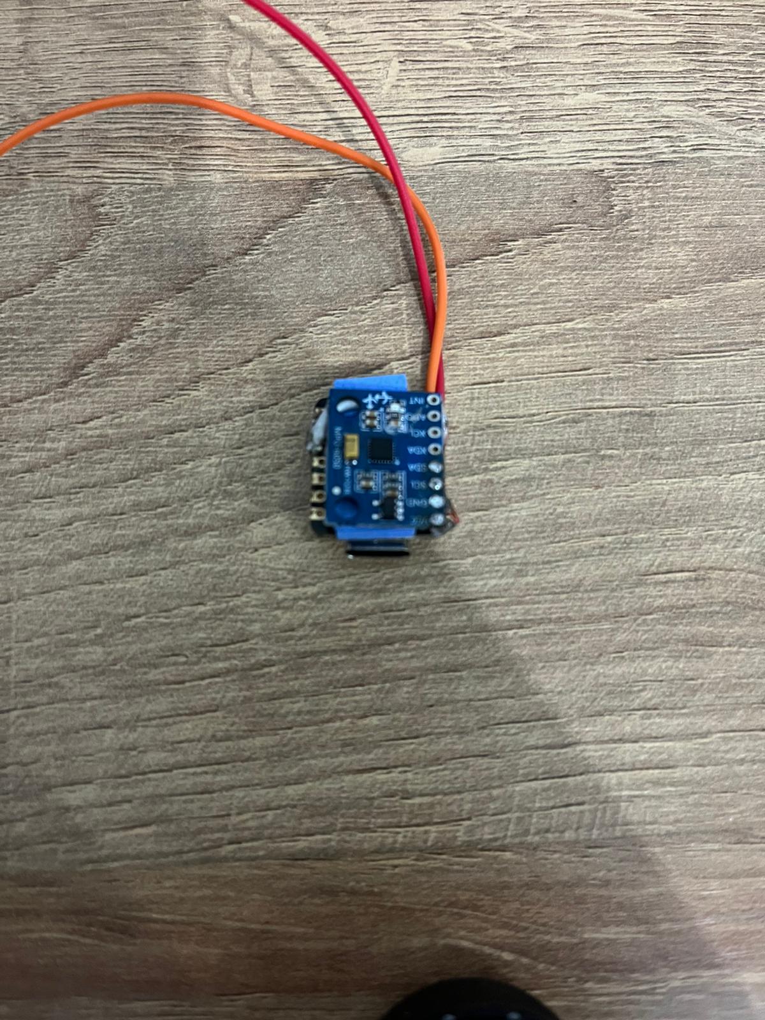
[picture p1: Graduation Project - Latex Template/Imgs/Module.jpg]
    
    \caption{\label{fig:module}A nail-mounted finger module: XIAO ESP32-C3
    stacked over an MPU6050 with an isolating pad between them.}
\end{figure}

% FIGURE — the fully assembled glove on the hand.
\begin{figure}[!htbp]
    \centering
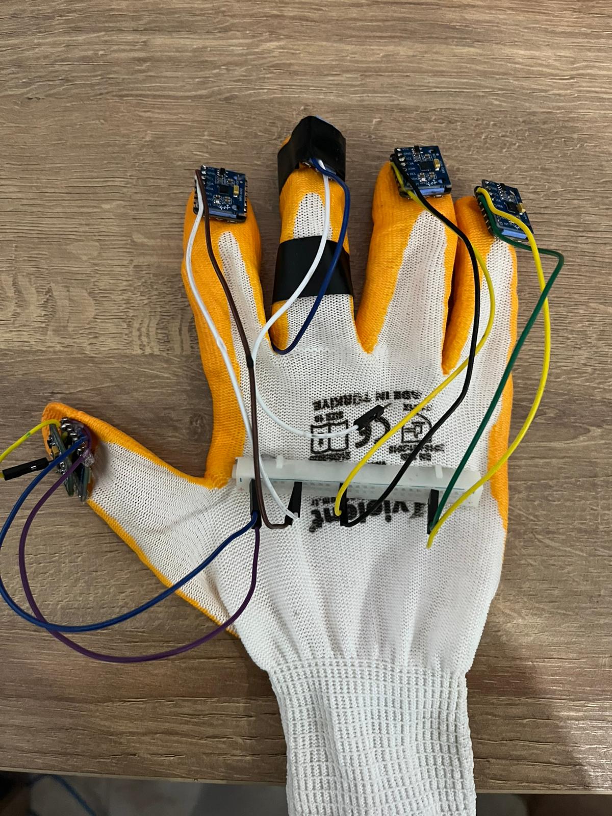
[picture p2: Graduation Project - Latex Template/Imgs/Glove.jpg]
    
    \caption{\label{fig:glove}The assembled glove. Five finger modules (thumb,
    index, ring, and pinky as slaves; middle as master) are mounted over the
    nails and wired to a single power rail.}
\end{figure}

\section{Network Topology: Master and Slaves}

The five modules form a star network on the hand. The \textbf{middle-finger
module is the master}; the \textbf{thumb, index, ring, and pinky modules are
slaves}. Each slave reads and fuses its own IMU and transmits a small packet to
the master over ESP-NOW at 25\,Hz. The master reads its own IMU, collects the
latest packet from each slave, and assembles a single 45-channel feature vector
(five fingers $\times$ nine fields), which it forwards to the phone over BLE.
This topology is illustrated in Figure~\ref{fig:arch} and summarised in
Table~\ref{tab:topology}.

% Architecture / data-flow diagram (native TikZ, no image file required).
\begin{figure}[!htbp]
\centering
\begin{tikzpicture}[
    font=\small,
    node distance=8mm,
    slave/.style={draw, rounded corners, align=center, minimum width=20mm,
                  minimum height=9mm, fill=black!4},
    master/.style={draw, very thick, rounded corners, align=center,
                   minimum width=26mm, minimum height=12mm, fill=black!8},
    sink/.style={draw, rounded corners, align=center, minimum width=22mm,
                 minimum height=10mm, fill=black!4},
    espnow/.style={-{Latex[length=2mm]}, thick},
    ble/.style={-{Latex[length=2.4mm]}, very thick},
]
    % Slaves on the left, stacked
    \node[slave] (thumb) {Thumb\\\scriptsize slave};
    \node[slave, below=of thumb] (index) {Index\\\scriptsize slave};
    \node[slave, below=of index] (ring)  {Ring\\\scriptsize slave};
    \node[slave, below=of ring]  (pinky) {Pinky\\\scriptsize slave};

    % Master in the middle
    \node[master, right=26mm of index, yshift=-7mm] (master)
        {Middle\\\textbf{master}\\\scriptsize +own IMU};

    % Phone on the right
    \node[sink, right=24mm of master] (phone)
        {Phone\\\scriptsize CNN + TTS};

    % ESP-NOW links from each slave to master
    \draw[espnow] (thumb.east) -- (master.west);
    \draw[espnow] (index.east) -- (master.west);
    \draw[espnow] (ring.east)  -- (master.west);
    \draw[espnow] (pinky.east) -- (master.west);

    % BLE link master -> phone
    \draw[ble] (master.east) -- node[above, midway] {\scriptsize BLE}
        node[below, midway] {\scriptsize 45-ch vector} (phone.west);

    % Labels
    \node[above=1mm of thumb, font=\scriptsize] {4 slaves $\times$ IMU @ 25\,Hz};
    \node[below=6mm of master, font=\scriptsize, align=center]
        {ESP-NOW broadcast\\(no per-link ACK retries)};
\end{tikzpicture}
\caption{\label{fig:arch}On-hand data flow. Four slave modules each fuse their
own IMU and broadcast a packet over ESP-NOW at 25\,Hz; the middle-finger master
adds its own IMU, assembles the 45-channel feature vector, and streams it to the
phone over BLE, where the quantised CNN classifies it and text-to-speech speaks
the result.}
\end{figure}

\begin{table}[!htbp]
\centering
\caption{\label{tab:topology}Network roles and data paths.}
\begin{tabular}{lll}
\toprule
Module (finger) & Role & Outgoing link \\
\midrule
Thumb (1)  & Slave  & ESP-NOW $\rightarrow$ master \\
Index (2)  & Slave  & ESP-NOW $\rightarrow$ master \\
Middle (3) & Master & BLE $\rightarrow$ phone \\
Ring (4)   & Slave  & ESP-NOW $\rightarrow$ master \\
Pinky (5)  & Slave  & ESP-NOW $\rightarrow$ master \\
\bottomrule
\end{tabular}
\end{table}

\section{Evolution of the Design}

The final architecture was reached iteratively, and the intermediate designs
are instructive.

\textbf{Iteration 1 — wrist hub with external antennas.} The first design used
a separate ESP32 development board worn at the wrist as a receiver, and clipped
an external U.FL antenna to each finger module to improve the radio link to the
wrist. Measurements revealed three problems: the wrist-to-fingertip distance
made the link sensitive to hand pose (a closed fist shadowed the inner
fingers); the five external antennas, bunched together when the hand closed,
coupled and interfered; and routing the antenna coax along moving fingers was
mechanically fragile.

\textbf{Iteration 2 — nail-mounted modules, no antennas, no hub.} Relocating
the receiver onto the middle fingertip reduced the worst-case link distance
from roughly 20\,cm (wrist) to a few centimetres (adjacent fingertip), which
made the on-chip antennas more than sufficient and removed the external
antennas and their coupling entirely. Because the master fingertip can talk to
the phone directly over BLE, the separate wrist hub was also eliminated. This
single change resolved the antenna-coupling, hand-shadowing, and
mechanical-fragility problems together, and reduced the part count.

\textbf{Sampling rate.} The data rate was reduced from an initial 50\,Hz to
25\,Hz. At 50\,Hz the master could not reliably both receive four ESP-NOW
streams and emit BLE notifications on a single radio; 25\,Hz leaves ample
headroom, and human hand motion is well below the resulting 12.5\,Hz Nyquist
limit, so no useful information is lost.

\section{Power}

For development and evaluation the glove is powered from a regulated 5\,V
supply over USB-C; each XIAO regulates this to 3.3\,V on-board. Power integrity
proved to be a practical constraint: the simultaneous radio transmissions of
several modules produce brief current spikes, and a marginal supply or wiring
path can sag the rail far enough to trigger the ESP32-C3 brown-out detector and
reset a module. The mitigations—reducing the Wi-Fi transmit power to a level
appropriate for a few-centimetre link, improving the power wiring, and adding
local decoupling capacitance—are discussed with the evaluation in Chapter~7.

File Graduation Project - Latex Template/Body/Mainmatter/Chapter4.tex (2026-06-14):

\chapter{Firmware and Sensor Signal Processing}

The firmware exists in two roles, sharing a common signal-processing core: the
\emph{slave} sketch (thumb, index, ring, pinky) and the \emph{master} sketch
(middle finger). Both are written for the Arduino-ESP32 framework.

\section{Per-Finger Signal Processing}

Every module, master or slave, processes its own IMU identically.

\subsection{Acquisition and Filtering}

The MPU6050 is read over I\textsuperscript{2}C at 25\,Hz. The on-sensor digital
low-pass filter is set to 10\,Hz, which removes high-frequency mechanical noise
before sampling. A bus-recovery routine bit-bangs the clock line and
re-initialises the sensor if a sequence of reads fails, so a transient
I\textsuperscript{2}C stall does not permanently disable a finger.

\subsection{Orientation Estimation}

Pitch and roll are estimated by fusing the accelerometer and gyroscope with a
two-state Kalman filter \cite{kalman} per axis, with the angle and the gyro
bias as states. When the magnitude of the measured acceleration departs from
$1\,g$ (indicating linear motion rather than pure gravity), the filter trusts
the gyroscope more and gates out the unreliable accelerometer tilt. Yaw, which
a six-axis IMU cannot reference absolutely, is obtained by integrating the
bias-corrected $z$-axis angular rate with a small dead-band, and is reset to
zero after a sustained period of stillness to bound its drift.

\subsection{Calibration and Bias Tracking}

At start-up each module performs a stillness calibration: it averages several
hundred samples to establish the zero references for pitch and roll and the
initial gyroscope bias, rejecting the attempt if the measured variance shows
the hand was moving. During operation, whenever the module detects stillness
(low angular rate and acceleration close to $1\,g$), it slowly updates the
gyroscope bias with an exponential moving average. This continuously tracks the
bias drift caused by the microcontroller warming the adjacent sensor, which is
significant for a low-cost gyroscope and is one reason motion-based features
later proved more robust than absolute-orientation features.

\subsection{Packet Format}

Each module produces, per cycle, a packet of nine fields: the three fused
angles (pitch, roll, yaw), the three bias-corrected angular rates
($g_x,g_y,g_z$), and the three accelerations ($a_x,a_y,a_z$). A slave sends
this as a small fixed-size structure tagged with its finger identifier and a
sequence number.

\section{The Slave Sketch}

A slave runs a deadline-scheduled 25\,Hz loop. Each cycle it reads and fuses
its IMU, builds its packet, and \emph{broadcasts} it over ESP-NOW on a fixed
Wi-Fi channel. Broadcasting rather than addressing the master directly was a
deliberate change: a unicast send waits for a link-layer acknowledgement and
retries on failure, and under the four-slave load these retries backed up the
transmit queue and exhausted the ESP-NOW send buffers (a recurring
\texttt{ESP\_ERR\_ESPNOW\_NO\_MEM}). A broadcast is fire-and-forget with no
per-link ACK or retry, which removed that failure entirely; the occasional lost
packet is harmless because the master always uses each finger's most recent
packet. A staggered start-up delay per finger reduces the chance that all four
slaves transmit in the same instant. The module also prints a periodic diagnostic line (read success rate,
transmit success/failure counts, current angles) over USB for bench debugging.

\section{The Master Sketch}

The master is dual-purpose, selected at compile time:

\begin{itemize}
    \item \textbf{CSV mode} streams every received packet, plus its own, as
    comma-separated lines over USB at 921600\,baud. This feeds the data-%
    collection script (Chapter~5). The high baud rate is necessary: at
    115200\,baud the five-finger stream saturates the USB serial buffer, the
    blocking print inside the receive callback backs up, and 15--30\% of
    packets are dropped—a failure that was diagnosed and fixed by raising the
    baud rate.
    \item \textbf{BLE mode} exposes a GATT service with a notify
    characteristic. Each 25\,Hz cycle the master reads its own IMU, packs the
    five fingers' nine fields into a 180-byte payload (45 little-endian 32-bit
    floats), and sends it as a BLE notification to the connected phone. A
    finger whose data has not arrived recently is sent as zeros so the payload
    is always well-formed.
\end{itemize}

\subsection{Aggregation and Channel Order}

The master keeps the latest packet from each finger in a lock-protected table.
The 45 channels are emitted in a fixed finger-major order—thumb, index, middle,
ring, pinky—each contributing $P,R,Y,g_x,g_y,g_z,a_x,a_y,a_z$. This exact order
is mirrored in the data-collection script and in the phone application, so that
the model sees identically ordered channels everywhere.

\subsection{Radio Coexistence and the BLE MTU}

The master runs ESP-NOW (Wi-Fi physical layer) reception and BLE transmission
on a single radio, which the ESP32-C3 time-slices. At 25\,Hz this is
comfortable. One non-obvious requirement is the BLE \emph{maximum transmission
unit}: the default 23-byte MTU carries only 20 payload bytes per notification,
far short of the 180-byte feature vector, so the phone must negotiate a larger
MTU (247 bytes requested, 256 granted) immediately after connecting. Without
this negotiation the notifications are truncated and silently rejected by the
phone—a failure that initially presented as ``no data'' despite a healthy
radio link.

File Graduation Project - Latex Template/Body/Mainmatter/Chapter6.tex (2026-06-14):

\chapter{Mobile Application}

The mobile application, built with Flutter for cross-platform deployment,
performs three roles: it manages the BLE link to the glove, it runs the
on-device neural network, and it presents recognised gestures as text and
speech.

\section{Architecture}

The application is organised into services with clear responsibilities: a BLE
service that handles scanning, connection, and packet parsing; an inference
service that buffers sensor frames and runs the model; a text-to-speech
service; and a preferences service that holds the per-model configuration. The
main screen is a single capture-and-display view; a segmented control switches
between the \emph{Letters} and \emph{Words} models.

\section{Bluetooth Link and Packet Parsing}

On connection the BLE service requests the appropriate runtime permissions,
scans for the glove by address (falling back to its advertised name), connects,
and—crucially—negotiates a larger MTU before subscribing to the notify
characteristic (Chapter~4). Each 180-byte notification is parsed into 45
little-endian floats forming one sensor frame, which is pushed into a fixed-%
size rolling buffer. Frames are rejected if their length is wrong or any value
is non-finite. The Android manifest declares the modern \texttt{BLUETOOTH\_%
SCAN} and \texttt{BLUETOOTH\_CONNECT} permissions; an early bug, in which the
app required a location permission that the manifest no longer declared on
recent Android, was traced to this and fixed.

\section{Gated Capture}

Rather than classifying continuously, the application uses \emph{gated
capture}, mirroring the data-collection procedure exactly. The user presses a
\textbf{Listen} button; the screen shows a brief countdown so the signer can
prepare, then a clear ``sign now'' cue while a fresh window of sensor frames is
collected; the model is then run once on that window. This guarantees that the
window seen at inference matches the window used during training, and it makes
the device's behaviour predictable and demonstrable. It also matches how
fingerspelling is naturally performed: one deliberate gesture at a time.

\section{On-Device Inference Pipeline}

When a window is captured, the inference service applies, in order: (i) the
per-model feature transform (the relative transform for a relative model, or
none for an absolute model), (ii) standard-scaler normalisation using the
model's exported statistics, (iii) quantisation of the normalised values to
int8 using the input tensor's scale and zero-point, (iv) execution of the
TensorFlow Lite model, and (v) dequantisation of the int8 output back to class
probabilities, followed by an arg-max. Each of these steps must agree exactly
with the training pipeline; the feature transform and the normalisation
statistics are therefore selected \emph{per model} (Section~\ref{sec:permodel}).

\section{Per-Model Configuration}\label{sec:permodel}

The Letters and Words models have different class sets, different normalisation
statistics, and—in principle—could use different feature transforms. The
application therefore swaps the model file, the label list, the normalisation
statistics, and the transform flag together whenever the user changes mode. A
subtle bug class this avoids is silently using one model's normalisation with
another model's weights; the normaliser is reset on each load so a failed swap
can never leave stale statistics in place.

\section{Output}

In Words mode, a recognised sign is spoken immediately through text-to-speech.
In Letters mode, recognised letters accumulate into a text buffer so the user
can fingerspell a word; a \textbf{Speak} button reads the assembled word aloud
and a \textbf{Clear} button empties the buffer to start again. A confidence
threshold suppresses low-confidence predictions so that an uncertain capture
asks the user to try again rather than committing a wrong letter.

Figure~\ref{fig:app} shows the application in use. In Words mode (left) the
recognised sign is shown in large type with a confidence bar beneath it and is
spoken at once; multi-word signs such as \textsc{how are you} are displayed and
spoken as spaced phrases rather than the run-together tokens the model emits. In
Letters mode (centre) each accepted letter is appended to the buffer shown at the
top, and the \textbf{Speak} and \textbf{Clear} controls let the user read back
or reset the assembled word. The Settings screen (right) exposes the confidence
threshold, the text-to-speech voice, and the Letters-mode auto-clear interval.
The same confidence threshold governs both modes, so the interface stays quiet
rather than guessing when a capture is ambiguous.

% FIGURE — mobile app screenshots (Words, Letters, Settings).
\begin{figure}[!htbp]
    \centering
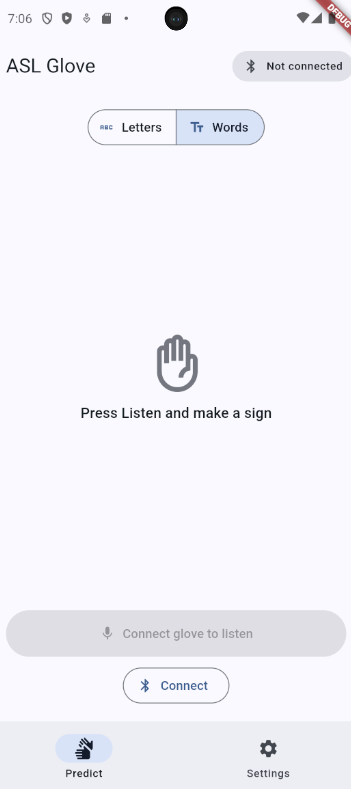
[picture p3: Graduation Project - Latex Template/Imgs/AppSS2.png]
    
    \hfill
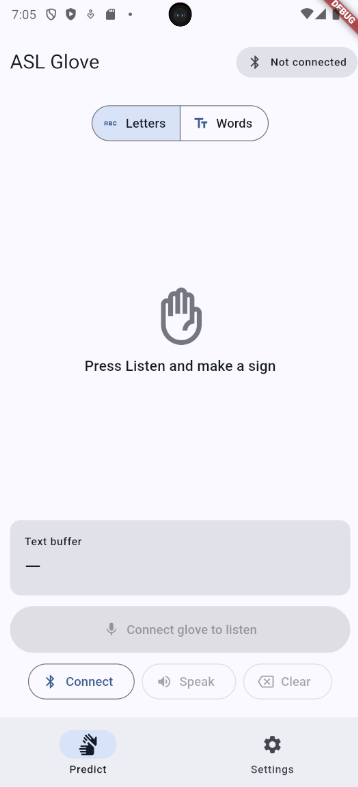
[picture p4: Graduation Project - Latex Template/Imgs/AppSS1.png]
    
    \hfill
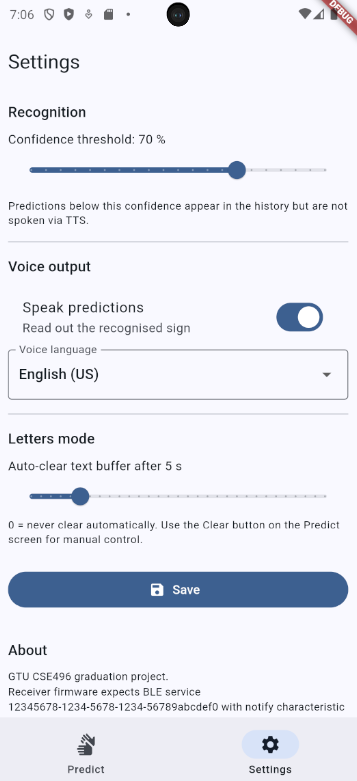
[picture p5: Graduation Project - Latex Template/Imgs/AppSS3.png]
    
    \caption{\label{fig:app}The mobile application. Left: Words mode, which speaks
    a recognised sign immediately. Centre: Letters mode, which accumulates
    fingerspelled letters into a buffer with \textbf{Speak} and \textbf{Clear}
    controls. Right: the Settings screen, exposing the confidence threshold,
    text-to-speech voice, and the Letters-mode auto-clear interval.}
\end{figure}

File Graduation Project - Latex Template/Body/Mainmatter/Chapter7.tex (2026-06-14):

\chapter{Results and Evaluation}

This chapter reports the measured behaviour of the system across four
dimensions: the wireless link, on-device model performance, recognition
accuracy, and power/thermal robustness. Where a result has an important
limitation, it is stated plainly.

\section{Wireless Link Reliability}

With the master in BLE mode and all four slaves powered, the master's periodic
diagnostics report the number of packets received from each finger over each
five-second window. In a healthy run every finger reports approximately 125
packets per five seconds—exactly the expected $25\,\text{Hz} \times 5\,\text{s}$
—with the per-finger loss counters at zero (Table~\ref{tab:rf}). The BLE link,
once the MTU is negotiated to 256 bytes, delivers the full 180-byte feature
vector per notification at the same 25\,Hz. The architecture change from a
wrist hub with external antennas to nail-mounted modules on the on-chip
antennas was decisive here: at the few-centimetre finger-to-finger distance the
link is no longer pose-dependent, and packet loss in the closed-fist
configuration—previously the worst case—is negligible.

\begin{table}[!htbp]
\centering
\caption{\label{tab:rf}Representative five-second link diagnostics from the
master (BLE connected).}
\begin{tabular}{lcc}
\toprule
Finger & Packets received & Lost \\
\midrule
Thumb  & 125 & 0 \\
Index  & 125 & 0 \\
Middle (own) & 125 & 0 \\
Ring   & 125 & 0 \\
Pinky  & 125 & 0 \\
\bottomrule
\end{tabular}
\end{table}

\section{On-Device Model Performance}

The deployed int8 model is small and fast (Table~\ref{tab:perf}). At roughly
1\,ms per inference against a 40\,ms (25\,Hz) frame budget, inference latency is
negligible, and the memory footprint is small enough for any modern phone. The
gated-capture design means inference runs once per user request rather than
continuously, so the practical compute and energy cost is lower still.

\begin{table}[!htbp]
\centering
\caption{\label{tab:perf}On-device characteristics of the quantised model
(Edge Impulse estimate, Raspberry Pi~4 class target).}
\begin{tabular}{lr}
\toprule
Metric & Value \\
\midrule
Inference time   & $\approx$ 1\,ms \\
Peak RAM         & 22.7\,KB \\
Flash (model)    & 137\,KB \\
Quantisation     & int8 (input and output) \\
\bottomrule
\end{tabular}
\end{table}

\section{Recognition Accuracy}

Several models were trained over the course of the project as the feature
representation evolved. Table~\ref{tab:acc} summarises the validation-set
accuracy of the main variants, as reported by Edge Impulse on the final
training run of each. The held-out split is taken \emph{before} augmentation,
so augmented copies of validation samples never appear in training and the
figures are not inflated by that form of leakage.

\begin{table}[!htbp]
\centering
\caption{\label{tab:acc}Edge Impulse validation-set accuracy of the main model
variants. All figures are within-session (the data is recorded in a single
session and split internally); they measure separability under fixed
calibration, not cross-session generalisation---see the caveat below.}
\begin{tabular}{lccc}
\toprule
Model & Classes & Features & Accuracy \\
\midrule
Smoke set        & 5  & raw / static     & high (pipeline validation) \\
Letters v2       & 26 & relative, static & $\approx$100\% \\
Words (final)    & 19 & absolute, dynamic& 100.0\% \\
Letters v3 (final)& 26 & absolute, dynamic& 100.0\% \\
\bottomrule
\end{tabular}
\end{table}

The accuracy figures alone do not show \emph{which} classes were confused, which
is where the feature representation made its difference. Figure~\ref{fig:cm}
shows the validation-set confusion matrices exported from Edge Impulse for the
final letters and words models. Both are fully diagonal: every class is
separated cleanly with no residual within-session confusions. This is exactly
what the move to dynamic gestures with absolute features bought, in contrast to
the systematic off-diagonal errors (e.g.\ T$\rightarrow$A,
YOU$\leftrightarrow$ME) that the earlier static and relative representations
produced. The meaningful residual errors are no longer within-session---they
appear only in live, cross-session use, which is discussed next.

% FIGURE — Edge Impulse confusion matrices (letters above, words below).
% Stacked rather than side-by-side so the dense 26-class letters matrix stays
% legible at full text width.
\begin{figure}[!htbp]
    \centering
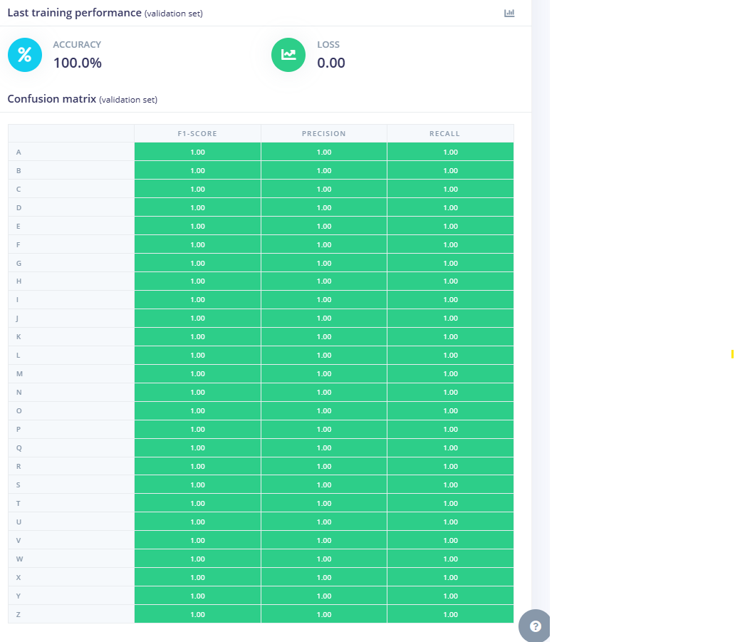
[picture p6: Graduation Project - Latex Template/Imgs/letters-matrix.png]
    \\[1.5ex]
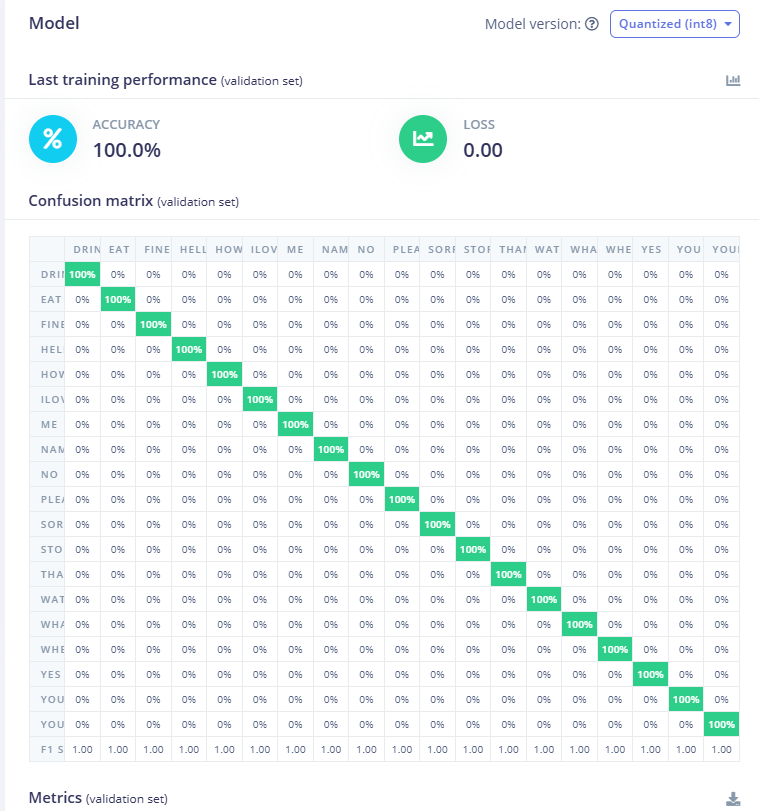
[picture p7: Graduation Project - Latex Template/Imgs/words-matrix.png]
    
    \caption{\label{fig:cm}Validation-set confusion matrices from Edge Impulse.
    Top: the 26-letter model. Bottom: the 19-word model. Both are fully
    diagonal---every class is recognised with no within-session confusion---so
    the residual errors of interest are the cross-session ones discussed in the
    live findings below, not anything visible here.}
\end{figure}

\subsection{The Single-Session Caveat}

The validation accuracies in Table~\ref{tab:acc} reach 100\%, but they are
\emph{within-session}: each validation split shares the same calibration,
mounting, and thermal state as its training set. This is the easiest possible test and must
not be read as the system's accuracy for a fresh user session. The honest
measure of generalisation is cross-session—training on one or more sessions and
testing on a different day with a fresh calibration—and the live testing
described next is the practical proxy for it.

\subsection{Live Findings and the Role of Feature Representation}

Live testing was the experiment that drove the project's main finding. The
static, absolute-feature letter model achieved high offline accuracy yet failed
live, confidently confusing letters because the calibration pose could not be
reproduced. Introducing the relative (orientation-invariant) transform removed
this calibration sensitivity, but the thumb-cluster letters
(\textbf{A}/\textbf{S}/\textbf{T}/\textbf{M}/\textbf{N}) remained confused
live, confirming that their separation is limited by sensor resolution rather
than by the feature transform. For the word model, the relative transform
introduced a different failure: signs distinguished only by global hand
orientation or translation (notably \textsc{you} vs \textsc{me}) collapsed,
because mean-centering deliberately discards exactly that information; switching
the word model to absolute features separated them again.

These observations converge on a single conclusion: for inertial sign
recognition on low-cost sensors, \emph{dynamic gestures with absolute features}
are the robust choice, because the discriminative information then resides in
the angular-rate channels, which are inherently independent of the start-up
calibration. Re-recording the alphabet as distinctive per-letter motions and
training on absolute features is the embodiment of this conclusion. A secondary
but practical finding is that a dynamic gesture must fill the capture window: a
sign with a long still tail drifts toward whichever class has the least motion,
which then acts as an attractor for ambiguous captures.

\section{Power and Thermal Behaviour}

The peak instantaneous current of the whole glove is dominated by simultaneous
radio transmissions. With the Wi-Fi transmit power at its maximum, a slave's
transmit burst draws on the order of 300\,mA; in the pathological case of all
four slaves transmitting in the same instant the system peak approaches
1.5\,A, although the phase-staggered transmissions make full alignment
momentary. The average draw is far lower, on the order of a few hundred
milliamps.

This peak is the source of the most disruptive failure observed: a marginal
supply or wiring path sags the 3.3\,V rail far enough during a transmit burst to
trip the ESP32-C3 brown-out detector and reset a module, which in the logs
appears as a repeated reboot and (on the affected board) erratic sensor reads.
Because the transmit current is the trigger, the primary mitigation is to
reduce the Wi-Fi transmit power: the finger-to-finger link spans only a few
centimetres and has tens of decibels of margin, so a much lower transmit power
both removes the current spike and reduces self-heating, with no loss of link
reliability. Improving the power wiring and adding local decoupling capacitance
at each module are complementary hardware mitigations. Reducing the transmit
power changes only the radio, not the sensor data, so it requires no
re-collection of data or re-training.

Separately, the proximity of the microcontroller to the IMU within each nail
module warms the gyroscope over a session, which shifts its zero-rate bias.
This is handled in firmware by the continuous still-state bias tracking
(Chapter~4) and is a further reason the motion-based, calibration-independent
features were preferred.

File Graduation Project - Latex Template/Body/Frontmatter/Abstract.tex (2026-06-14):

\chapter*{Abstract}
\addcontentsline{toc}{chapter}{Abstract}

%% Edit below this line
Sign language is the primary means of communication for millions of deaf and
hard-of-hearing people, yet the scarcity of interpreters in everyday settings
creates a persistent barrier with the hearing world. This project presents a
self-contained, wearable glove that recognises American Sign Language (ASL)
gestures and translates them into spoken output in real time, without a camera
or any external infrastructure.

The system places a compact inertial measurement unit (MPU6050) and a
microcontroller (Seeed Studio XIAO ESP32-C3) on the nail of each of the five
fingers. Four ``slave'' modules stream fused orientation and angular-rate data
over the ESP-NOW protocol to a fifth ``master'' module on the middle finger,
which aggregates a 45-channel feature vector at 25\,Hz and forwards it to a
mobile phone over Bluetooth Low Energy. A Flutter application captures a
fixed-length window of sensor data on demand, runs a quantised one-dimensional
convolutional neural network entirely on-device, and speaks the recognised
letter or word through text-to-speech.

A central finding of the work is the decisive role of the feature
representation. Static handshape recognition based on absolute finger
orientation proved fragile, because the inertial reference frame cannot be
reproduced exactly between sessions and because the limited angular resolution
of the sensors cannot separate handshapes that differ only by small thumb
displacements. The project therefore adopts distinctive per-letter
\emph{motions} together with \emph{absolute} (non-orientation-normalised)
features, relocating the discriminative information into the
calibration-independent angular-rate channels. The deployed models occupy
137\,KB of flash, require 22.7\,KB of RAM, and execute in approximately 1\,ms
per inference; the wireless link delivers all five finger streams at 25\,Hz
with negligible packet loss. The project demonstrates that accurate,
low-latency, fully on-device sign-language translation is achievable on
inexpensive commodity hardware, and it documents the engineering trade-offs—%
radio coexistence, power integrity, thermal behaviour, and feature
invariance—that govern such a system.

%% Until here
\vfill
%% Edit after {Keywords:}
\textbf{Keywords:} sign language recognition, wearable computing, inertial
measurement unit, ESP-NOW, Bluetooth Low Energy, edge machine learning,
one-dimensional convolutional neural network, gesture recognition.
\clearpage

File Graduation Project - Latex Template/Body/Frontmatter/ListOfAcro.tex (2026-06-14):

\chapter*{List of Symbols and Abbreviations}
\addcontentsline{toc}{chapter}{List of Symbols and Abbreviations}

\begin{tabular}{lcl}
    \textbf{Symbol or}&&\\
    \textbf{Abbreviation} &:& \textbf{Explanation}\\

    %% Edit below in the format
    %% XYZ &:& EXPLANATION\\

    ASL    &:& American Sign Language\\
    IMU    &:& Inertial Measurement Unit\\
    MCU    &:& Microcontroller Unit\\
    BLE    &:& Bluetooth Low Energy\\
    GATT   &:& Generic Attribute Profile (BLE)\\
    MTU    &:& Maximum Transmission Unit\\
    CNN    &:& Convolutional Neural Network\\
    1-D CNN&:& One-Dimensional Convolutional Neural Network\\
    DOF    &:& Degrees of Freedom\\
    DLPF   &:& Digital Low-Pass Filter\\
    DSP    &:& Digital Signal Processing\\
    EI     &:& Edge Impulse (model development platform)\\
    TFLite &:& TensorFlow Lite\\
    int8   &:& 8-bit integer (quantised) representation\\
    TTS    &:& Text-to-Speech\\
    USB    &:& Universal Serial Bus\\
    CDC    &:& Communications Device Class (USB serial)\\
    RF     &:& Radio Frequency\\
    LDO    &:& Low-Dropout (voltage regulator)\\
    BOD    &:& Brown-Out Detector\\
    RMS    &:& Root Mean Square\\
    $f_s$  &:& Sampling frequency (25\,Hz)\\
    P, R, Y&:& Pitch, Roll, Yaw (Euler angles)\\
    $g_x,g_y,g_z$ &:& Angular rate about the $x$, $y$, $z$ axes\\
    $a_x,a_y,a_z$ &:& Linear acceleration along the $x$, $y$, $z$ axes\\

    %% Until here
\end{tabular}

\clearpage

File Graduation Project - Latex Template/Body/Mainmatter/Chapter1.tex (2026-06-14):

\chapter{Introduction}

\section{Motivation}

According to the World Health Organization, more than 5\% of the world's
population lives with disabling hearing loss. For many of these people, a
signed language—rather than a written or spoken one—is their first and most
natural means of communication. American Sign Language (ASL) is a complete,
grammatically rich language used by a large community across North America and
beyond. Despite this, communication between signers and the hearing majority
remains difficult in everyday situations such as shops, clinics, and public
offices, because qualified interpreters are scarce and cannot be present on
demand.

Technology offers a path to narrow this gap. If a wearable device could
recognise signed gestures and render them as speech, a signer could be
understood by a hearing person who knows no sign language, with no third party
required. Such a device must be \emph{portable}, \emph{low-latency},
\emph{affordable}, and ideally \emph{self-contained}, so that it works anywhere
without a network connection or a fixed camera installation. These constraints
motivate the design presented in this thesis: a glove that senses hand and
finger motion with small inertial sensors and performs the entire recognition
pipeline on-device.

\section{Problem Statement}

The core problem is to translate a vocabulary of ASL gestures into text and
speech using only wearable inertial sensing, subject to the practical
constraints of a battery- or USB-powered wearable. Concretely, the system must:

\begin{itemize}
    \item sense the configuration and motion of the five fingers with
    sufficient fidelity to distinguish a useful vocabulary of letters and
    words;
    \item transmit that data wirelessly and reliably from the hand to a
    processing device;
    \item classify gestures accurately and with low latency;
    \item operate without a camera, a cloud service, or a wired tether during
    use; and
    \item remain robust to the practical realities of a wearable—imperfect
    re-calibration between uses, limited power, and the heat generated by the
    on-hand electronics.
\end{itemize}

\section{Objectives and Scope}

The objectives of this project are:

\begin{enumerate}
    \item To design and build a five-finger sensing glove based on commodity
    inertial measurement units and microcontrollers.
    \item To establish a reliable wireless data path from the glove to a mobile
    phone.
    \item To collect a labelled dataset of ASL gestures and to train a compact
    neural network suitable for on-device inference.
    \item To develop a mobile application that performs inference and produces
    spoken output.
    \item To evaluate the accuracy, latency, and practical robustness of the
    complete system, and to document the engineering decisions and trade-offs
    encountered.
\end{enumerate}

The scope is limited to a single hand, a fixed vocabulary of fingerspelling
letters and a set of common one-handed word signs, and recognition of
deliberate, segmented gestures (one gesture captured per request) rather than
continuous, unsegmented signing.

\section{Contributions}

The principal contributions of this work are:

\begin{itemize}
    \item A \textbf{no-hub, master/slave wearable architecture} in which one
    finger module aggregates the data of the other four and bridges directly
    to a phone, eliminating the separate wrist-mounted receiver and the
    external antennas of earlier iterations.
    \item An empirical study of \textbf{feature representation} for
    inertial sign recognition, showing why orientation-normalised
    (``relative'') features and absolute features each succeed or fail
    depending on whether a gesture is static or dynamic, and arriving at a
    \emph{dynamic-gesture, absolute-feature} formulation that is robust to
    imperfect re-calibration.
    \item A \textbf{train/inference-parity pipeline} in which the exact
    windowing, feature transform, and normalisation used during data
    collection are reproduced on the phone, together with a quantised model
    that runs in roughly one millisecond on-device.
    \item A documented account of the \textbf{system-level engineering
    trade-offs}—radio coexistence, USB throughput, power integrity, and
    thermal behaviour—that are rarely reported but decisive in practice.
\end{itemize}

\section{Thesis Outline}

Chapter~2 reviews sign-language recognition approaches, inertial sensing, and
edge machine learning. Chapter~3 describes the system requirements and the
hardware architecture, including the evolution of the design. Chapter~4 details
the firmware and the sensor signal-processing chain. Chapter~5 presents the
data-acquisition pipeline, the feature-representation study, and the neural
network. Chapter~6 describes the mobile application and the on-device inference
path. Chapter~7 reports and discusses the evaluation results. Chapter~8
concludes and outlines future work.

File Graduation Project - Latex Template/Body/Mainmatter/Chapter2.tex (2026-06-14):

\chapter{Background and Related Work}

\section{Sign Language and Fingerspelling}

A signed language conveys meaning through handshape, orientation, location,
movement, and non-manual markers such as facial expression. ASL has a
dedicated set of one-handed handshapes for the letters of the alphabet, used
for \emph{fingerspelling}—spelling out words letter by letter—which is common
for names and for words that lack a dedicated sign. Most letters are static
handshapes; two, \textbf{J} and \textbf{Z}, are defined by a traced motion.
Word-level signs are typically dynamic and may be one- or two-handed. Because
the device in this project instruments a single hand, the vocabulary is
restricted to fingerspelling and to one-handed word signs.

A practical consequence for sensing is that several fingerspelling letters
differ only in subtle thumb placement against a closed fist—for example
\textbf{A}, \textbf{S}, \textbf{T}, \textbf{M}, and \textbf{N}. The ability of
any sensing modality to separate these handshapes is therefore a key indicator
of its resolution.

\section{Approaches to Sign Language Recognition}

Sign-language recognition (SLR) systems fall broadly into two families.

\textbf{Vision-based} systems use one or more cameras and computer-vision or
deep-learning models to interpret hand and body pose. They require no
instrumentation of the signer but depend on controlled lighting, a clear line
of sight, and significant computation, and they raise privacy concerns because
they continuously capture video.

\textbf{Sensor-based (glove)} systems instrument the hand directly with
sensors such as flex sensors, which measure finger bend, or inertial
measurement units (IMUs), which measure orientation and motion. Gloves work in
any lighting, do not capture the surroundings, and can run on small
microcontrollers, at the cost of requiring the user to wear the device. This
project adopts the glove approach using IMUs, which—unlike flex sensors—capture
both static finger orientation and dynamic motion, and are available as
inexpensive, easily interfaced modules.

\section{Inertial Measurement Units and Sensor Fusion}

An IMU such as the InvenSense MPU6050 \cite{mpu6050} integrates a three-axis
gyroscope and a three-axis accelerometer. The accelerometer measures the
gravity vector (giving an absolute tilt reference) plus linear acceleration;
the gyroscope measures angular rate. Neither sensor alone yields a stable
orientation: accelerometer-only tilt is corrupted by motion, while integrating
the gyroscope alone accumulates drift.

\emph{Sensor fusion} combines the two to obtain a stable estimate. The Kalman
filter \cite{kalman} is the classical optimal estimator for this purpose and is
widely used to fuse accelerometer and gyroscope measurements into pitch and
roll angles. A practical complication is that the gyroscope's zero-rate bias
drifts with temperature; this is commonly mitigated by continuously
re-estimating the bias whenever the device is detected to be still. Both
techniques are used in this project's firmware (Chapter~4).

A fundamental limitation of a six-axis IMU is that yaw (rotation about the
gravity axis) cannot be referenced absolutely without a magnetometer, and that
small static orientation differences are near the noise floor of a low-cost
part. These limitations directly shape the feature-representation findings of
Chapter~5.

\section{Wireless Protocols for Wearables}

Body-worn sensor networks require a short-range, low-power link. Two relevant
technologies are used here. \textbf{ESP-NOW} \cite{espnow} is a connectionless,
low-latency protocol built on the Wi-Fi physical layer by Espressif, well
suited to many-to-one streaming between ESP32-family devices without the
overhead of a full Wi-Fi association. \textbf{Bluetooth Low Energy (BLE)} is
the standard for communicating with smartphones; its GATT profile exposes
\emph{characteristics} that a phone can subscribe to for streaming
notifications. The system in this thesis uses ESP-NOW for finger-to-finger
communication and BLE for the final hop to the phone (Chapter~3).

\section{Machine Learning at the Edge}

Running inference on a constrained device (``edge'' or ``TinyML'') requires
small models and efficient execution. Two ideas are central. First,
\textbf{one-dimensional convolutional neural networks (1-D CNNs)} are an
effective and lightweight architecture for time-series and human-activity
recognition \cite{ronao2016, hatcnn}, learning local temporal patterns with far
fewer parameters than recurrent models. Second, \textbf{quantisation} converts
a trained 32-bit floating-point model to 8-bit integers, shrinking it roughly
four-fold and accelerating inference, usually with negligible accuracy loss;
TensorFlow Lite \cite{tflite} provides this conversion and a portable runtime.
The models in this project are 1-D CNNs trained with the Edge Impulse platform
\cite{edgeimpulse} and deployed as int8 TensorFlow Lite files inside a mobile
application.

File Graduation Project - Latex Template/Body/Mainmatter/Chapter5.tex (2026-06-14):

\chapter{Data Acquisition, Feature Engineering, and Modelling}

This chapter describes how gesture data is collected, how it is represented,
and how the recognition model is trained and deployed. The feature-%
representation study in Section~\ref{sec:features} is the central technical
contribution of the project.

\section{Data Acquisition}

Data is collected with the master in CSV mode (Chapter~4) connected to a
laptop, driven by a Python recorder. The operator selects a label, the recorder
shows a short countdown, and a fixed-length window is captured while the
gesture is performed. Each saved sample is a CSV file of 75 rows
($3\,\text{s} \times 25\,\text{Hz}$) and 45 channels. The recorder forward-fills
the most recent packet from each finger onto a uniform time grid and flags
samples in which any finger's data went stale, so that dropped-packet windows
can be discarded.

\section{Signal Window and Channels}

A gesture is represented by a $75 \times 45$ window: 75 time steps of the 45
channels defined in Chapter~4. This window length and channel order are fixed
across data collection, training, and on-device inference. Matching them
exactly—\emph{train/inference parity}—is essential; a mismatch in window
length, sampling rate, or channel order silently degrades or breaks live
accuracy even when offline metrics look perfect.

\section{Feature Representation}\label{sec:features}

The most important design question proved to be \emph{what} the model sees, not
which classifier is used.

\subsection{The Problem with Absolute Orientation for Static Handshapes}

A natural first representation is the absolute fused orientation of each finger.
This failed in live use for static fingerspelling in two distinct ways. First,
the absolute pitch/roll of each finger is measured relative to the start-up
calibration pose, which a user cannot reproduce exactly between sessions; a few
degrees of difference in how the hand is held shifts every channel and causes
confident misclassification. Second, even with perfect calibration, letters
that differ only by small thumb placement (e.g.\ \textbf{A} vs \textbf{T}) lie
within the angular noise floor of the sensors and cannot be separated.

\subsection{Relative (Orientation-Invariant) Features}

To address the calibration sensitivity, an orientation-invariant transform was
introduced. For the orientation-bearing channels ($P,R,Y,a_x,a_y,a_z$), the
per-time-step mean across the five fingers is subtracted, leaving only the
\emph{inter-finger} differences; the angular-rate channels are left unchanged.
Because a global rotation of the hand (or a calibration offset) adds the same
amount to all five fingers, subtracting their mean cancels it, while the
relative finger configuration—which defines the handshape—is preserved. This
made static-letter features invariant to global hand tilt and to the
calibration pose.

Relative features removed the calibration sensitivity but, as expected, could
not overcome the sensor-resolution limit: the thumb-cluster letters remained
confusable, because the information that separates them was never captured by
the sensors in the first place.

\subsection{Dynamic Gestures with Absolute Features}

The resolution of both problems was to change the gestures rather than only the
features. Each letter (except the inherently dynamic \textbf{J} and \textbf{Z})
was re-recorded as a short, distinctive \emph{motion} that engages specific
fingers—for example a thumb fold, an index-and-thumb tap, or a thumb-and-pinky
meeting—so that the discriminative information lives in the angular-rate
($g$) channels. The angular rate is a measurement of motion and is inherently
independent of the start-up calibration, so \emph{absolute} features (no
mean-centering) can be used. This dynamic-gesture, absolute-feature formulation
is used for both the letter and the word models. A small number of practical
rules emerged: the motion must fill the whole capture window (a gesture with a
long still tail collapses toward a low-motion ``attractor'' class), and within
a confusable group the motions must differ clearly in axis, direction, or
repetition count.

The same logic was confirmed for word signs. Word pairs distinguished only by
global hand orientation or translation (e.g.\ \textsc{you} vs \textsc{me})
collapsed under mean-centering—which deliberately discards exactly that
information—and were correctly separated once absolute features were used.

\section{Augmentation and Dataset Splitting}

Recording every gesture across many sessions is time-consuming, so synthetic
augmentation is used to improve robustness to session-to-session variation.
For each training sample, several copies are generated with small random
per-finger angle offsets, small per-finger gyroscope-bias offsets, and
per-reading sensor noise—simulating realistic calibration and thermal variance
without re-recording. Critically, the train/test split is performed
\emph{before} augmentation and on the original samples only, so that no
augmented copy of a test sample can appear in training. This leakage-safe
procedure keeps the held-out test set an honest measure of generalisation.

\section{Network Architecture}

The classifier is a compact one-dimensional convolutional neural network
\cite{ronao2016}. The flattened input is reshaped to $75 \times 45$ and passed
through two convolutional blocks—each a 1-D convolution, batch normalisation,
max-pooling, and dropout (16 then 32, or 32 then 64, filters, kernel size
3)—followed by a flatten, a dense layer, dropout, and a softmax output over the
classes. The architecture was authored in Keras through Edge Impulse's expert
mode \cite{edgeimpulse}. Training uses categorical cross-entropy with the Adam
optimiser, a 20\% validation split, and standard-scaler normalisation of the
inputs, whose per-channel means and standard deviations are exported so the
phone can reproduce the identical normalisation at inference time.

\section{Quantisation and Deployment}

The trained model is exported as an 8-bit-integer (int8) quantised TensorFlow
Lite file \cite{tflite}. Quantisation reduces the model size roughly four-fold
and speeds up inference, and on this data it incurred no measurable accuracy
loss. The deployed model occupies about 137\,KB of flash and 22.7\,KB of RAM
and runs in approximately 1\,ms per inference (Chapter~7). Because the model's
input and output tensors are both int8, the application must quantise the
normalised input and dequantise the output using the scale and zero-point
published in the model—handled in the mobile application (Chapter~6).

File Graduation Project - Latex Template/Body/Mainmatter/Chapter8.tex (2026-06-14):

\chapter{Conclusion and Future Work}

\section{Summary}

This project set out to translate American Sign Language gestures into speech
using only a wearable inertial glove, with the entire recognition pipeline
running on commodity hardware and a phone. The resulting system places a
microcontroller-and-IMU module on each fingernail, streams four fingers' data
over ESP-NOW to a fifth ``master'' finger, and bridges to a mobile phone over
Bluetooth Low Energy, where a quantised one-dimensional convolutional neural
network classifies a captured window and speaks the result. The wireless link
delivers all five finger streams at 25\,Hz with negligible loss, and the
deployed model runs in about one millisecond using tens of kilobytes of memory.

Beyond the working system, the project's most valuable outcome is a clear,
empirically grounded understanding of \emph{feature representation} for
inertial sign recognition. Through successive live failures and fixes, the work
established that absolute-orientation features for static handshapes are
fragile against imperfect re-calibration and limited by sensor resolution; that
an orientation-invariant relative transform fixes the calibration problem but
not the resolution problem, and harms dynamic signs that depend on global
motion; and that the robust formulation is to perform gestures as distinctive
\emph{motions} and classify them on \emph{absolute} features, placing the
decisive information in the calibration-independent angular-rate channels.

\section{Limitations}

Several limitations are acknowledged honestly. First, the reported accuracies
are within-session; rigorous cross-session and cross-user evaluation remains to
be done, and is expected to lower the figures. Second, the device instruments a
single hand and recognises segmented, one-gesture-at-a-time input, not
continuous or two-handed signing. Third, fingerspelling letters that differ
only by fine thumb placement are at the limit of what six-axis IMUs can resolve
statically; the project mitigates this by encoding letters as distinct motions,
but this departs from the canonical static handshapes. Fourth, power integrity
under simultaneous radio transmissions is a real constraint that requires
attention to the supply and wiring. Finally, recognition operates at the level
of single letters and words without higher-level language modelling.

\section{Future Work}

\begin{itemize}
    \item \textbf{Cross-session and multi-user data.} Collecting several
    sessions on different days, and data from multiple wearers, would both
    improve robustness and provide an honest generalisation measure to replace
    the within-session figures.
    \item \textbf{Word-level language modelling.} A dictionary- or trie-based
    decoder over the letter stream would resolve residual letter confusions at
    the word level, since context disambiguates letters that are individually
    ambiguous—mirroring how human readers parse fingerspelling.
    \item \textbf{Power hardening and battery operation.} Fixing the supply and
    wiring, adding decoupling, lowering the transmit power, and adding a
    listen-triggered sleep mode would enable untethered battery operation and
    reduce heat, allowing longer continuous use.
    \item \textbf{Larger and two-handed vocabulary.} Extending to a larger word
    set and, with a second instrumented hand, to two-handed signs would broaden
    practical usefulness.
    \item \textbf{Continuous recognition.} Moving from gated, segmented capture
    to continuous gesture spotting would make the device feel more natural,
    at the cost of a harder segmentation and modelling problem.
\end{itemize}

\section{Concluding Remarks}

The project delivers a complete, self-contained sign-language translation glove
and, just as importantly, a documented account of why it is built the way it
is. The system evolved through measured failures—antenna coupling, USB
throughput, BLE MTU, calibration drift, sensor resolution, and power
integrity—each of which was diagnosed and resolved with an understood
engineering trade-off rather than a guess. That process, and the
feature-representation conclusion it produced, is the work's main contribution
and the strongest foundation for the future work above.

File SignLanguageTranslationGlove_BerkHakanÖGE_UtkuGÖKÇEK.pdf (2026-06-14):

T.R.

# GEBZE TECHNICAL UNIVERSITY

# FACULTY OF ENGINEERING

# DEPARTMENT OF COMPUTER ENGINEERING

# ASL GLOVE: A WEARABLE AMERICAN SIGN

# LANGUAGE TRANSLATOR USING INERTIAL

# SENSING AND ON-DEVICE DEEP LEARNING

# BERK HAKAN ÖGE - UTKU GÖKÇEK

# SUPERVISOR

# DR. ÖĞR. ÜYESI ALP ARSLAN BAYRAKÇİ

# GEBZE

2026

T.R.

# GEBZE TECHNICAL UNIVERSITY

# FACULTY OF ENGINEERING

# COMPUTER ENGINEERING DEPARTMENT

# ASL GLOVE: A WEARABLE AMERICAN

# SIGN LANGUAGE TRANSLATOR USING

# INERTIAL SENSING AND ON-DEVICE

# DEEP LEARNING

# BERK HAKAN ÖGE - UTKU GÖKÇEK

# SUPERVISOR DR. ÖĞR. ÜYESI ALP ARSLAN BAYRAKÇİ

2026

# GEBZE

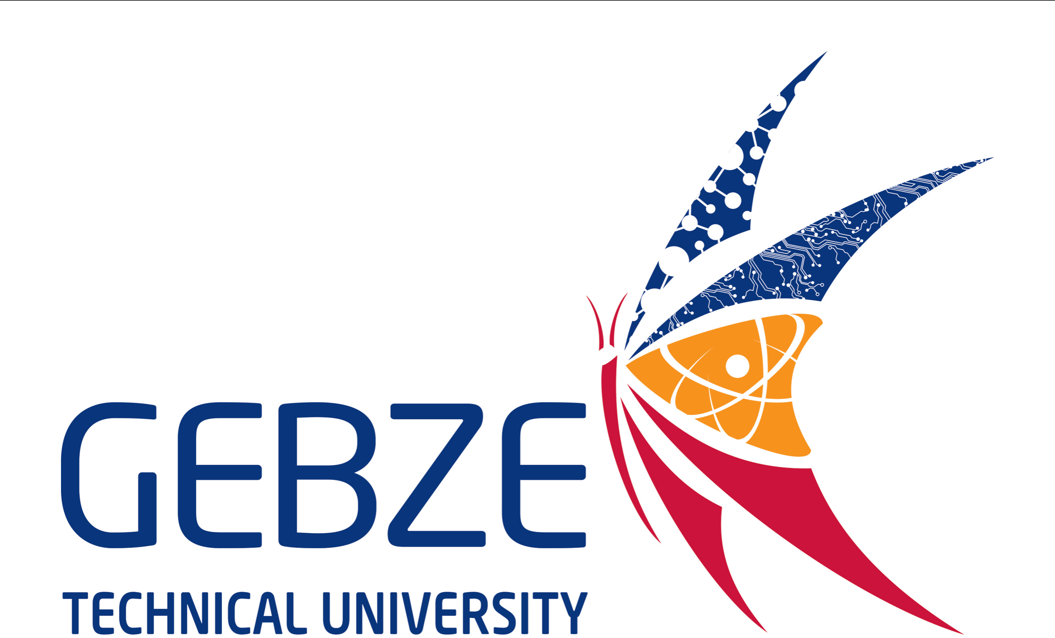
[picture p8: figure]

## GRADUATION PROJECT

## JURY APPROVAL FORM

This study has been accepted as an Undergraduate Graduation Project in the

Department of Computer Engineering on 18/06/2026 by the following jury.

# JURY

Member

(Supervisor) : | Dr. Öğr. Üyesi Alp Arslan BAYRAKÇİ
Member | : | Dr. Öğr. Üyesi Alp Arslan BAYRAKÇİ
Member | : | Prof. Dr. Erkan ZERGEROĞLU

# ABSTRACT

Sign language is the primary means of communication for millions of deaf and

hard-of-hearing people, yet the scarcity of interpreters in everyday settings creates

a persistent barrier with the hearing world. This project presents a self-contained,

wearable glove that recognises American Sign Language (ASL) gestures and translates

them into spoken output in real time, without a camera or any external infrastructure.

The system places a compact inertial measurement unit (MPU6050) and a mi-

crocontroller (Seeed Studio XIAO ESP32-C3) on the nail of each of the five fingers.

Four “slave” modules stream fused orientation and angular-rate data over the ESP-NOW

protocol to a fifth “master” module on the middle finger, which aggregates a 45-channel

feature vector at 25 Hz and forwards it to a mobile phone over Bluetooth Low Energy.

A Flutter application captures a fixed-length window of sensor data on demand, runs a

quantised one-dimensional convolutional neural network entirely on-device, and speaks

the recognised letter or word through text-to-speech.

A central finding of the work is the decisive role of the feature representation.

Static handshape recognition based on absolute finger orientation proved fragile, be-

cause the inertial reference frame cannot be reproduced exactly between sessions and

because the limited angular resolution of the sensors cannot separate handshapes that

differ only by small thumb displacements. The project therefore adopts distinctive per-

letter motions together with absolute (non-orientation-normalised) features, relocating

the discriminative information into the calibration-independent angular-rate channels.

The deployed models occupy 137 KB of flash, require 22.7 KB of RAM, and execute

in approximately 1 ms per inference; the wireless link delivers all five finger streams at

25 Hz with negligible packet loss. The project demonstrates that accurate, low-latency,

fully on-device sign-language translation is achievable on inexpensive commodity hard-

ware, and it documents the engineering trade-offs—radio coexistence, power integrity,

thermal behaviour, and feature invariance—that govern such a system.

Keywords: sign language recognition, wearable computing, inertial measure-

ment unit, ESP-NOW, Bluetooth Low Energy, edge machine learning, one-dimensional

convolutional neural network, gesture recognition.

iv

# ÖZET

İşaret dili, milyonlarca işitme engelli birey için temel iletişim aracıdır; ancak

günlük hayatta tercüman bulunmaması, işiten dünya ile aralarında sürekli bir iletişim

engeli oluşturmaktadır. Bu proje, Amerikan İşaret Dili (ASL) hareketlerini tanıyıp

gerçek zamanlı olarak sesli çıktıya dönüştüren, kamera veya herhangi bir dış altyapı

gerektirmeyen, kendi kendine yeten giyilebilir bir eldiven sunmaktadır.

Sistem, beş parmağın her birinin tırnağına kompakt bir eylemsizlik ölçüm birimi

## (MPU6050) ve bir mikrodenetleyici (Seeed Studio XIAO ESP32-C3) yerleştirir. Dört

“uydu” modül, füzyonlanmış yönelim ve açısal hız verilerini ESP-NOW protokolü

üzerinden orta parmaktaki beşinci “ana” modüle iletir. Ana modül, 25 Hz hızında 45

kanallı bir öznitelik vektörü oluşturarak bunu Bluetooth Düşük Enerji (BLE) üzerinden

bir akıllı telefona aktarır. Bir Flutter uygulaması, istek üzerine sabit uzunlukta bir

sensör penceresi yakalar, nicelenmiş tek boyutlu bir evrişimsel sinir ağını tamamen

cihaz üzerinde çalıştırır ve tanınan harf veya kelimeyi metinden konuşmaya çevirme ile

seslendirir.

Çalışmanın temel bulgularından biri, öznitelik temsilinin belirleyici önemidir.

Mutlak parmak yönelimine dayalı statik el şekli tanıma, eylemsizlik referans çerçevesinin

oturumlar arasında tam olarak yeniden üretilememesi ve sensörlerin sınırlı açısal

çözünürlüğünün yalnızca küçük başparmak hareketleriyle ayrılan el şekillerini ayırt

edememesi nedeniyle kırılgan kalmıştır. Bu nedenle proje, ayırt edici bilgiyi kali-

brasyondan bağımsız açısal hız kanallarına taşıyan, harfe özgü belirgin hareketler

## ile mutlak öznitelikleri benimsemiştir. Dağıtılan modeller 137 KB flash ve 22.7 KB

RAM kullanır ve çıkarım başına yaklaşık 1 ms sürede çalışır; kablosuz bağlantı beş

parmağın tüm akışlarını 25 Hz hızında ihmal edilebilir paket kaybıyla iletir. Proje,

düşük maliyetli, yaygın donanım üzerinde doğru, düşük gecikmeli ve tamamen ci-

haz içi işaret dili çevirisinin uygulanabilir olduğunu göstermekte ve böyle bir sistemi

yöneten mühendislik ödünleşimlerini—radyo birlikte çalışabilirliği, güç bütünlüğü,

termal davranış ve öznitelik değişmezliği—belgelemektedir.

## Anahtar Kelimeler: işaret dili tanıma, giyilebilir teknoloji, eylemsizlik ölçüm

## birimi, ESP-NOW, Bluetooth Düşük Enerji, uç birim makine öğrenmesi, tek boyutlu

evrişimsel sinir ağı, hareket tanıma.

v

# ACKNOWLEDGEMENT

We would like to express our sincere gratitude to our supervisor for the guidance,

patience, and constructive feedback offered throughout this project. We also thank the

Department of Computer Engineering at Gebze Technical University for providing the

environment and resources that made this work possible. Finally, we are deeply grateful

to our families and friends for their continuous support and encouragement during our

studies.

# Berk Hakan Öge

# Utku Gökçek

vi

# LIST OF SYMBOLS AND ABBREVIATIONS

# Symbol or

Abbreviation : | Explanation
ASL | : | American Sign Language
IMU | : | Inertial Measurement Unit
MCU | : | Microcontroller Unit
BLE | : | Bluetooth Low Energy
GATT | : | Generic Attribute Profile (BLE)
MTU | : | Maximum Transmission Unit
CNN | : | Convolutional Neural Network
1-D CNN | : | One-Dimensional Convolutional Neural Network
DOF | : | Degrees of Freedom
DLPF | : | Digital Low-Pass Filter
DSP | : | Digital Signal Processing
EI | : | Edge Impulse (model development platform)
TFLite | : | TensorFlow Lite
int8 | : | 8-bit integer (quantised) representation
TTS | : | Text-to-Speech
USB | : | Universal Serial Bus
CDC | : | Communications Device Class (USB serial)
RF | : | Radio Frequency
LDO | : | Low-Dropout (voltage regulator)
BOD | : | Brown-Out Detector
RMS | : | Root Mean Square
fs | : | Sampling frequency (25 Hz)
P, R, Y | : | Pitch, Roll, Yaw (Euler angles)
gx, gy, gz | : | Angular rate about the x, y, z axes
ax, ay, az | : | Linear acceleration along the x, y, z axes

## vii

# CONTENTS

Abstract | iv
Özet | v
Acknowledgement | vi
List of Symbols and Abbreviations | vii
Contents | x
List of Figures | xi
List of Tables | xii
1 Introduction | 1
2 Background and Related Work | 4
3 System Overview and Hardware Architecture | 7

## viii

4 Firmware and Sensor Signal Processing | 12
5 Data Acquisition, Feature Engineering, and Modelling | 15
5.3.1 | The Problem with Absolute Orientation for Static Handshapes | 15
6 Mobile Application | 18
7 Results and Evaluation | 21
8 Conclusion and Future Work | 26

ix

Bibliography | 28
Appendices | 29

x

# LIST OF FIGURES

3.1 | A nail-mounted finger module: | XIAO ESP32-C3 stacked over an
MPU6050 with an isolating pad between them. | | | 8
3.2 | The assembled glove. | Five finger modules (thumb, index, ring, and

pinky as slaves; middle as master) are mounted over the nails and

wired to a single power rail | | 9
3.3 | On-hand data flow. Four slave modules each fuse their own IMU and

broadcast a packet over ESP-NOW at 25 Hz; the middle-finger master

adds its own IMU, assembles the 45-channel feature vector, and streams

it to the phone over BLE, where the quantised CNN classifies it and

text-to-speech speaks the result. | | | 10
6.1 | The mobile application. Left: Words mode, which speaks a recognised
sign immediately. | Centre: | Letters mode, which accumulates finger-
spelled letters into a buffer with Speak and Clear controls. | Right:

the Settings screen, exposing the confidence threshold, text-to-speech

voice, and the Letters-mode auto-clear interval. | | | 20
7.1 | Validation-set confusion matrices from Edge Impulse. | Top: the 26-

letter model. Bottom: the 19-word model. Both are fully diagonal—

every class is recognised with no within-session confusion—so the

residual errors of interest are the cross-session ones discussed in the

live findings below, not anything visible here. | | | 23

xi

# LIST OF TABLES

3.1 | Network roles and data paths | | 9
7.1 | Representative five-second link diagnostics from the master (BLE con-
nected). | | | 21
7.2 | On-device characteristics of the quantised model (Edge Impulse esti-
mate, Raspberry Pi 4 class target). | | | 22
7.3 | Edge Impulse validation-set accuracy of the main model variants. All

figures are within-session (the data is recorded in a single session and

split internally); they measure separability under fixed calibration, not

cross-session generalisation—see the caveat below. | | | 22

## xii

# 1. INTRODUCTION

# 1.1. Motivation

According to the World Health Organization, more than 5% of the world’s pop-

ulation lives with disabling hearing loss. For many of these people, a signed lan-

guage—rather than a written or spoken one—is their first and most natural means of

communication. American Sign Language (ASL) is a complete, grammatically rich

language used by a large community across North America and beyond. Despite this,

communication between signers and the hearing majority remains difficult in everyday

situations such as shops, clinics, and public offices, because qualified interpreters are

scarce and cannot be present on demand.

Technology offers a path to narrow this gap. If a wearable device could recognise

signed gestures and render them as speech, a signer could be understood by a hearing

person who knows no sign language, with no third party required. Such a device must be

# portable, low-latency, affordable, and ideally self-contained, so that it works anywhere

without a network connection or a fixed camera installation. These constraints motivate

the design presented in this thesis: a glove that senses hand and finger motion with

small inertial sensors and performs the entire recognition pipeline on-device.

# 1.2. Problem Statement

The core problem is to translate a vocabulary of ASL gestures into text and speech

using only wearable inertial sensing, subject to the practical constraints of a battery- or

USB-powered wearable. Concretely, the system must:

- sense the configuration and motion of the five fingers with sufficient fidelity to

distinguish a useful vocabulary of letters and words;

- transmit that data wirelessly and reliably from the hand to a processing device;
- classify gestures accurately and with low latency;
- operate without a camera, a cloud service, or a wired tether during use; and
- remain robust to the practical realities of a wearable—imperfect re-calibration

between uses, limited power, and the heat generated by the on-hand electronics.

# 1.3. Objectives and Scope

The objectives of this project are:

1. To design and build a five-finger sensing glove based on commodity inertial

measurement units and microcontrollers.

2. To establish a reliable wireless data path from the glove to a mobile phone.
3. To collect a labelled dataset of ASL gestures and to train a compact neural

network suitable for on-device inference.

4. To develop a mobile application that performs inference and produces spoken

output.

5. To evaluate the accuracy, latency, and practical robustness of the complete system,

and to document the engineering decisions and trade-offs encountered.

The scope is limited to a single hand, a fixed vocabulary of fingerspelling letters

and a set of common one-handed word signs, and recognition of deliberate, segmented

gestures (one gesture captured per request) rather than continuous, unsegmented sign-

ing.

# 1.4. Contributions

The principal contributions of this work are:

# - A no-hub, master/slave wearable architecture in which one finger module

aggregates the data of the other four and bridges directly to a phone, eliminating

the separate wrist-mounted receiver and the external antennas of earlier iterations.

- An empirical study of feature representation for inertial sign recognition, show-

ing why orientation-normalised (“relative”) features and absolute features each

succeed or fail depending on whether a gesture is static or dynamic, and arriving
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

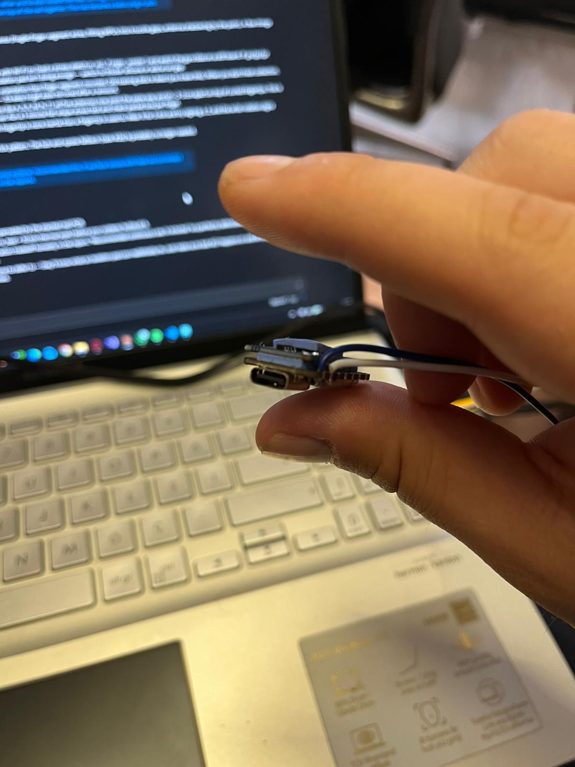
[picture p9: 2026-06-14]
new_architecture.jpeg

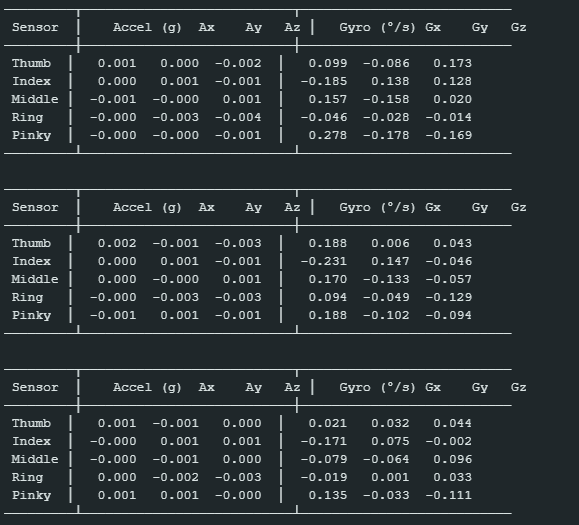
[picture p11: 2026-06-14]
docs/images/Ekran görüntüsü 2026-03-22 154523.png

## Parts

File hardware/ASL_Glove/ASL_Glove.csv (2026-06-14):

Id | Designator | Footprint | Quantity | Designation | Supplier and ref
1 | C1, C3, C4 | C_0402_1005Metric | 3 | 100nF
2 | C2 | C_0402_1005Metric | 1 | 10uF
3 | J1 | JST_PH_S2B-PH-K_1x02_P2.00mm_Horizontal | 1 | Conn_01x02
4 | R1, R2 | R_0402_1005Metric | 2 | 4.7k
5 | R3 | R_0402_1005Metric | 1 | 10k
6 | TP1 | TestPoint_Pad_D1.0mm | 1 | TX
7 | TP2 | TestPoint_Pad_D1.0mm | 1 | RX
8 | TP3 | TestPoint_Pad_D1.0mm | 1 | GND
9 | TP4 | TestPoint_Pad_D1.0mm | 1 | 3V3
10 | U1 | ESP32-C3-MINI-1 | 1 | ESP32-C3-MINI-1
11 | U2 | InvenSense_QFN-24_4x4mm_P0.5mm | 1 | MPU-6050

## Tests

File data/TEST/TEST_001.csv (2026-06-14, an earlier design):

timestamp | thumb_P | thumb_R | thumb_Y | thumb_gx | thumb_gy | thumb_gz | thumb_ax | thumb_ay | thumb_az | index_P | index_R | index_Y | index_gx | index_gy | index_gz | index_ax | index_ay | index_az | middle_P | middle_R | middle_Y | middle_gx | middle_gy | middle_gz | middle_ax | middle_ay | middle_az | ring_P | ring_R | ring_Y | ring_gx | ring_gy | ring_gz | ring_ax | ring_ay | ring_az | pinky_P | pinky_R | pinky_Y | pinky_gx | pinky_gy | pinky_gz | pinky_ax | pinky_ay | pinky_az | palm_P | palm_R | palm_Y | palm_gx | palm_gy | palm_gz | palm_ax | palm_ay | palm_az
0 | -4.5580 | 84.3640 | -64.6050 | 1.6220 | -0.5820 | -0.6720 | 2.9310 | 8.8300 | 3.4620 | -1.9360 | -53.4060 | 24.8460 | 1.5510 | 0.0980 | -0.4670 | 1.6420 | -9.6580 | 0.5750 | 11.1830 | -91.9090 | 16.1820 | 1.2070 | -0.3450 | 0.0700 | -3.0240 | -8.5400 | -3.2200 | -58.4410 | -81.7070 | -46.6160 | 0.8100 | 0.0750 | 1.0400 | 3.1320 | -8.4850 | -3.6890 | -9.9160 | -59.8980 | 24.6180 | 1.3010 | -0.0710 | -0.0300 | -0.4070 | -9.3920 | 2.8160 | -4.7990 | 59.5580 | 41.1260 | 0.8820 | 0.4000 | 0.5910 | -2.0490 | 9.6080 | 5.8490
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

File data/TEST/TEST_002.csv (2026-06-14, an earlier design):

timestamp | thumb_P | thumb_R | thumb_Y | thumb_gx | thumb_gy | thumb_gz | thumb_ax | thumb_ay | thumb_az | index_P | index_R | index_Y | index_gx | index_gy | index_gz | index_ax | index_ay | index_az | middle_P | middle_R | middle_Y | middle_gx | middle_gy | middle_gz | middle_ax | middle_ay | middle_az | ring_P | ring_R | ring_Y | ring_gx | ring_gy | ring_gz | ring_ax | ring_ay | ring_az | pinky_P | pinky_R | pinky_Y | pinky_gx | pinky_gy | pinky_gz | pinky_ax | pinky_ay | pinky_az | palm_P | palm_R | palm_Y | palm_gx | palm_gy | palm_gz | palm_ax | palm_ay | palm_az
0 | -44.1150 | 89.0480 | -30.5450 | 0.5000 | 0.8240 | -0.0530 | 8.8510 | 5.1910 | 1.6970 | -1.4520 | 96.0550 | 14.6710 | 0.0340 | 0.7610 | -0.2360 | 2.1140 | 8.4590 | 4.8770 | -8.5820 | 74.9540 | 31.1260 | -0.9760 | 1.5820 | 0.9780 | -1.6500 | 7.1250 | 6.6990 | -24.1320 | -83.5900 | 65.0380 | -1.3010 | 0.0890 | -0.6590 | -2.9660 | -8.1470 | -4.0150 | 5.8990 | -37.8760 | 59.8500 | -1.3440 | -1.2980 | 0.6160 | -3.2320 | -7.1350 | 5.7510 | 19.5330 | 49.5150 | 39.9340 | -0.8220 | 1.0500 | -0.3400 | -2.2410 | 9.1340 | 7.3450
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

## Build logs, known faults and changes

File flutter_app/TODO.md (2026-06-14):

# Flutter app — gated-capture rework (TODO)

Status: **planned, not yet implemented.** App currently does continuous
sliding-window inference. We are switching to button-gated, single-shot
capture that mirrors `scripts/record.py` exactly.

## Why this change

Train/inference parity. `record.py` captures one deterministic window per
sample (press → prep → GO → fixed window → STOP → one inference). If the app
captures the same way, the model sees the same data structure at inference
that it saw at training. This also eliminates the sliding-window alignment
problem (dynamic letters flipping to their static twin when motion ends
mid-window) — with gated capture the whole gesture lives inside one window,
exactly like training.

## Target UX

### Letters mode (fingerspelling)
```
[Listen] -> 3-2-1 countdown + GO cue -> capture window -> STOP cue
        -> single letter appended to on-screen buffer
[Listen] -> ... -> next letter appended
...
[Speak]  -> TTS reads the assembled word
[Clear]  -> empties the letter buffer to start a new word
```

### Words mode
```
[Listen] -> 3-2-1 countdown + GO cue -> capture window -> STOP cue
        -> recognized word shown
        -> TTS speaks it automatically (no separate button needed)
```

## Capture timing — MIRROR record.py

- prep: 1.0 s countdown (on-screen "3-2-1" + audible/haptic GO at window start)
- window: 3.0 s == AppConfig.windowTimesteps (75) @ 25 Hz. MUST equal the
  training window. If we ever shorten this, shorten record.py AND retrain.
- After STOP: snapshot the rolling buffer over the captured window, run the
  model ONCE, emit a single Prediction.
- BLE keeps streaming the whole time. The button gates *inference only*, not
  the radio — do not start/stop BLE on each press (avoids reconnect latency).

## Recording-pose protocol (so app capture matches dataset capture)

- Glove is always powered up / calibrated in the **signing-rest position:
  palm facing forward, fingers relaxed**. This is the pitch/roll zero
  reference — must be identical at dataset capture AND at demo inference.
- **Static letters** (A, B, C, ... except J, Z and the dynamic pair members):
  form the letter shape and hold it still for the whole window.
- **Dynamic letters** (J, Z, plus whichever confusable-pair members we mark
  as "moving"): start in the signing-rest position (palm forward) and perform
  the motion during the window.

## Code changes required (do NOT implement yet)

### lib/services/inference_service.dart
- Remove the periodic Timer (`start()` / `stop()` continuous loop).
- Add `Future<Prediction?> captureOnce()`:
  - (optional) prep delay handled by caller / UI
  - collect a full window of frames (windowTimesteps) from the rolling buffer
    starting at the GO instant — i.e. wait `windowDuration`, then snapshot.
  - run the model once, return one Prediction (or null if buffer not full).
- Keep `pushFrame()` filling the rolling buffer continuously from BLE.

### lib/screens/predict_screen.dart
- Replace the predictions-stream listener + threshold/_lastEmittedLabel/
  auto-clear logic with explicit button handlers.
- Add **Listen** button: runs countdown -> GO cue -> captureOnce() ->
  append result.
  - Letters mode: append single label char to `_letterBuffer`.
  - Words mode: show the word and auto-TTS it.
- Add **Speak** button (letters mode only): TTS the assembled `_letterBuffer`.
- Add **Clear** button (letters mode): empties `_letterBuffer` to start a new
  word. (Replaces the old auto-clear-timer behavior; manual control.)
- Show countdown / GO / STOP state visibly (big cue, not subtle) so the user
  knows exactly when to sign. This is the #1 reliability factor — copy the
  feel of record.py's prep beep.

### lib/config/app_config.dart
- Add capture timing constants if not already derivable
  (prepDuration = 1.0 s, windowDuration derived from windowTimesteps / 25 Hz).

### Cosmetic / cleanup
- The SegmentedButton (Letters/Words) stays as the mode switch.
- The continuous "model is predicting" history list can stay as a debug view
  or be removed — decide during implementation.

## Deferred / parked (not required now)
- Per-letter audio confirmation (soft tone or spoken letter on each capture).
  Keep word-only TTS for now.
- Light-sleep power management on the XIAOs (only if heat becomes a problem).
- Re-adding BLE GATT server to the middle-master firmware (task #24) — needed
  before any of this works live; right now master is in CSV-over-USB mode.

## Dependency note
This rework is BLOCKED on task #24 (BLE GATT server on the middle-finger
master). The app can be coded and tested against a mock/replayed stream, but
live demo needs the master broadcasting BLE notifications again. Sequence:
finish dataset + model -> re-add BLE to master -> implement this gated-capture
UI -> live demo.

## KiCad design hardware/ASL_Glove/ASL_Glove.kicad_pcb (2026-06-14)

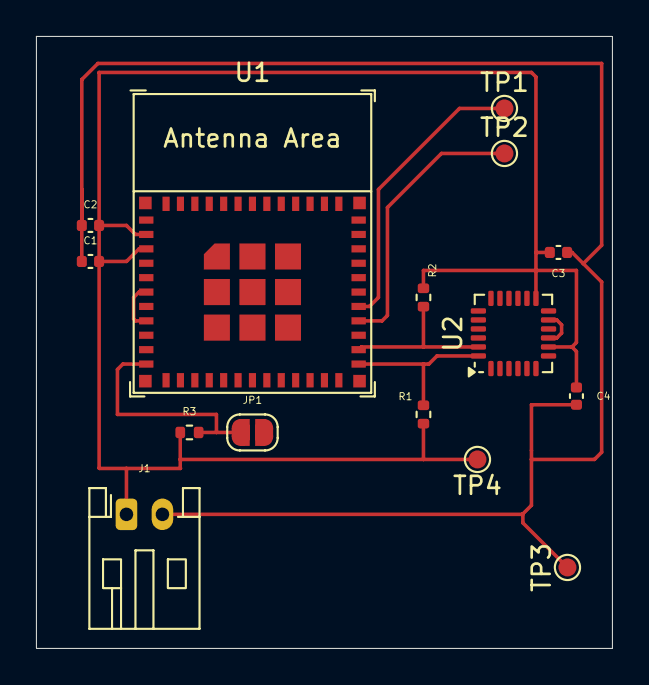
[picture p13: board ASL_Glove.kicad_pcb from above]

Board: 2 copper layers, 32.0 x 34.0 mm, 15 parts (0 on the bottom side), 7 nets.

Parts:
C1, C3, C4: 100nF; C_0402_1005Metric
C2: 10uF; C_0402_1005Metric
J1: Conn_01x02; JST_PH_S2B-PH-K_1x02_P2.00mm_Horizontal
JP1: ROLE_SEL; SolderJumper-2_P1.3mm_Open_RoundedPad1.0x1.5mm
R1, R2: 4.7k; R_0402_1005Metric
R3: 10k; R_0402_1005Metric
TP1: TX; TestPoint_Pad_D1.0mm
TP2: RX; TestPoint_Pad_D1.0mm
TP3: GND; TestPoint_Pad_D1.0mm
TP4: 3V3; TestPoint_Pad_D1.0mm
U1: ESP32-C3-MINI-1
U2: MPU-6050; InvenSense_QFN-24_4x4mm_P0.5mm

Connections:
+3V3: C1.2, C2.2, C3.2, C4.1, J1.1, R1.1, R2.1, R3.1, TP4.1 (1_1), U1.2 (3V3), U1.3 (3V3), U2.8 (VLOGIC), U2.13 (VDD)
GND: C1.1, C2.1, C3.1, C4.2, J1.2, JP1.2 (B), TP3.1 (1_1), U1.1 (GND), U1.6 (GND), U1.8 (GND), U1.12 (GND), U1.15 (GND), U1.16 (GND), U1.19 (GND), U1.24 (GND), U1.27 (GND), U1.30 (GND), U2.9 (AD0), U2.11 (FSYNC), U2.18 (GND)
unnamed: JP1.1 (A), R3.2, U1.11 (IO10)
unnamed: R1.2, U1.25 (IO8), U2.24 (SDA)
unnamed: R2.2, U1.26 (IO9), U2.23 (SCL)
unnamed: TP2.1 (1_1), U1.28 (RX)
unnamed: TP1.1 (1_1), U1.29 (TX)

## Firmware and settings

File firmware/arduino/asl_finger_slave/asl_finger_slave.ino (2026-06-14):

// ASL glove — finger SLAVE (XIAO ESP32-C3)
//
// Variant of asl_finger_sender that BROADCASTS its packets; the middle-finger
// MASTER receives them. Used in the "no-DevKit" architecture where the middle
// XIAO bridges 5 fingers to the phone over BLE. Broadcast (vs unicast) avoids
// MAC-layer ACK retries — the cause of ESP_ERR_ESPNOW_NO_MEM and a finger
// dropping to rx=0 at the master — and needs no per-board master MAC.
//
// Flash to thumb (FINGER_ID=1), index (=2), ring (=4), pinky (=5).
// DO NOT flash with FINGER_ID=3 — that's the master.
//
// Setup steps:
//   1. Set FINGER_ID per board (1=thumb, 2=index, 4=ring, 5=pinky).
//   2. Flash, repeat for the four slave fingers. No master MAC needed —
//      slaves broadcast and the master listens.
//
// Period dropped from 20 ms (50 Hz) → 40 ms (25 Hz) to leave headroom on
// the master for BLE notifications without needing light-sleep tricks.

#include <Arduino.h>
#include <WiFi.h>
#include <esp_now.h>
#include <esp_wifi.h>
#include <Wire.h>
#include <math.h>

// ---- USER CONFIG ---------------------------------------------------------- 58:8C:81:AD:E1:20
#define FINGER_ID 5                            // 1=thumb 2=index 4=ring 5=pinky
// TX power for this board's ESP-NOW radio. 8.5 dBm has ample margin at the
// few-cm finger-to-master range and roughly halves the ~335 mA TX spike that
// sagged marginal boards into brown-out. Raise a SINGLE board here only if the
// master heartbeat shows that finger losing packets.
#define TX_POWER WIFI_POWER_19_5dBm
// --------------------------------------------------------------------------

// Slaves broadcast (no per-board master MAC needed). Broadcast is
// fire-and-forget: no MAC-layer ACK, hence no ACK-retry queue build-up and
// less radio-on time per packet. The master receives broadcast and unicast
// identically, so the recorded data is unchanged.
static uint8_t BCAST_MAC[6] = {0xFF,0xFF,0xFF,0xFF,0xFF,0xFF};

static const uint8_t  ESPNOW_CHANNEL = 11;
static const uint32_t SEND_PERIOD_US = 40000;   // 25 Hz

static const int      SDA_PIN = 6;              // D4 on XIAO ESP32-C3
static const int      SCL_PIN = 7;              // D5 on XIAO ESP32-C3
static const uint32_t I2C_HZ  = 400000;

static uint8_t MPU = 0x68;   // auto-detected (0x68 or 0x69) at boot
static const uint8_t REG_SMPLRT_DIV  = 0x19;
static const uint8_t REG_CONFIG      = 0x1A;
static const uint8_t REG_GYRO_CONFIG = 0x1B;
static const uint8_t REG_ACCEL_CONFIG= 0x1C;
static const uint8_t REG_PWR_MGMT_1  = 0x6B;
static const uint8_t REG_WHO_AM_I    = 0x75;
static const uint8_t REG_ACCEL_XOUT  = 0x3B;
static const float ACCEL_LSB_PER_G  = 8192.0f;
static const float G_TO_MS2         = 9.80665f;
static const float GYRO_LSB_PER_DPS = 65.5f;

static const float    ACCEL_GATE_MS2 = 1.5f;
static const float    STILL_GYRO_DPS = 1.0f;
static const float    STILL_ACC_MS2  = 0.3f;
static const float    YAW_DEADBAND   = 5.0f;
static const float    YAW_MAX        = 180.0f;
static const uint32_t STILL_RESET_MS = 3000;
static const float    BIAS_EMA       = 0.005f;

typedef struct __attribute__((packed)) {
  uint8_t  finger_id;
  uint32_t seq;
  uint32_t t_ms;
  float    pitch, roll, yaw;
  float    gx, gy, gz;
  float    ax, ay, az;
} FingerPacket;

struct Kalman {
  float Q_angle = 0.001f, Q_bias = 0.003f, R_measure = 0.03f;
  float angle = 0.0f, bias = 0.0f;
  float P[2][2] = {{1,0},{0,1}};
  float predict(float rate, float dt) {
    float r = rate - bias;
    angle += dt * r;
    P[0][0] += dt * (dt*P[1][1] - P[0][1] - P[1][0] + Q_angle);
    P[0][1] -= dt * P[1][1];
    P[1][0] -= dt * P[1][1];
    P[1][1] += Q_bias * dt;
    return angle;
  }
  float update(float meas, float rate, float dt) {
    predict(rate, dt);
    float S = P[0][0] + R_measure;
    float K0 = P[0][0] / S, K1 = P[1][0] / S;
    float y = meas - angle;
    angle += K0 * y; bias += K1 * y;
    float P00 = P[0][0], P01 = P[0][1];
    P[0][0] -= K0 * P00; P[0][1] -= K0 * P01;
    P[1][0] -= K1 * P00; P[1][1] -= K1 * P01;
    return angle;
  }
};

Kalman kPitch, kRoll;
float pitchOff = 0, rollOff = 0;
float gxBias = 0, gyBias = 0, gzBias = 0;
float yaw = 0, fPitch = 0, fRoll = 0;
uint32_t txOk = 0, txFailCb = 0, txFailImm = 0;
uint32_t txConsecFail = 0;   // consecutive esp_now_send failures (radio stuck)
uint32_t i2cOk = 0, i2cFail = 0;
unsigned long lastUs = 0, nextUs = 0;
unsigned long stillSince = 0, windowStart = 0;
bool stillFlag = false;
uint32_t seq = 0;
FingerPacket pkt;

static bool mpuWrite(uint8_t reg, uint8_t val) {
  Wire.beginTransmission(MPU); Wire.write(reg); Wire.write(val);
  return Wire.endTransmission() == 0;
}
static bool mpuRead(uint8_t reg, uint8_t* buf, size_t n) {
  Wire.beginTransmission(MPU); Wire.write(reg);
  if (Wire.endTransmission(false) != 0) return false;
  size_t got = Wire.requestFrom((int)MPU, (int)n, (int)true);
  if (got != n) return false;
  for (size_t i = 0; i < n; i++) buf[i] = Wire.read();
  return true;
}
static bool readImu(float& ax, float& ay, float& az,
                    float& gx, float& gy, float& gz) {
  uint8_t b[14];
  if (!mpuRead(REG_ACCEL_XOUT, b, 14)) return false;
  int16_t rax = (int16_t)((b[0]  << 8) | b[1]);
  int16_t ray = (int16_t)((b[2]  << 8) | b[3]);
  int16_t raz = (int16_t)((b[4]  << 8) | b[5]);
  int16_t rgx = (int16_t)((b[8]  << 8) | b[9]);
  int16_t rgy = (int16_t)((b[10] << 8) | b[11]);
  int16_t rgz = (int16_t)((b[12] << 8) | b[13]);
  ax = (rax / ACCEL_LSB_PER_G) * G_TO_MS2;
  ay = (ray / ACCEL_LSB_PER_G) * G_TO_MS2;
  az = (raz / ACCEL_LSB_PER_G) * G_TO_MS2;
  gx = rgx / GYRO_LSB_PER_DPS;
  gy = rgy / GYRO_LSB_PER_DPS;
  gz = rgz / GYRO_LSB_PER_DPS;
  return true;
}

// Probe both possible MPU addresses (0x68 = AD0 low, 0x69 = AD0 high/floating)
// and use whichever ACKs — no AD0 soldering needed, and the same firmware runs
// on a board wired either way (e.g. the S3-Zero board reads 0x69).
static bool detectMpu() {
  Wire.beginTransmission(0x68);
  if (Wire.endTransmission() == 0) { MPU = 0x68; return true; }
  Wire.beginTransmission(0x69);
  if (Wire.endTransmission() == 0) { MPU = 0x69; return true; }
  return false;
}

static bool configMpu() {
  if (!detectMpu()) return false;   // sets MPU to 0x68 or 0x69
  uint8_t who = 0;
  if (!mpuRead(REG_WHO_AM_I, &who, 1)) return false;
  Serial.printf("MPU @ 0x%02X  WHO_AM_I = 0x%02X\n", MPU, who);
  if (!mpuWrite(REG_PWR_MGMT_1, 0x01)) return false;
  delay(10);
  mpuWrite(REG_SMPLRT_DIV,  0x00);
  mpuWrite(REG_CONFIG,      0x05);   // DLPF 10 Hz
  mpuWrite(REG_GYRO_CONFIG, 0x08);
  mpuWrite(REG_ACCEL_CONFIG,0x08);
  delay(50);
  return true;
}

static void recoverI2C() {
  Wire.end();
  pinMode(SCL_PIN, OUTPUT_OPEN_DRAIN);
  pinMode(SDA_PIN, INPUT_PULLUP);
  digitalWrite(SCL_PIN, HIGH); delayMicroseconds(10);
  for (int i = 0; i < 9; i++) {
    digitalWrite(SCL_PIN, LOW);  delayMicroseconds(5);
    digitalWrite(SCL_PIN, HIGH); delayMicroseconds(5);
  }
  Wire.begin(SDA_PIN, SCL_PIN, I2C_HZ);
  Wire.setTimeOut(50);
  configMpu();
}

static bool calibrateStill() {
  const int N = 300;
  double sax=0, say=0, saz=0;
  double sgx=0, sgy=0, sgz=0;
  double sgx2=0, sgy2=0, sgz2=0;
  int ok = 0;
  for (int i = 0; i < N; i++) {
    float ax,ay,az,gx,gy,gz;
    if (!readImu(ax,ay,az,gx,gy,gz)) { delay(5); continue; }
    sax += ax; say += ay; saz += az;
    sgx += gx; sgy += gy; sgz += gz;
    sgx2 += (double)gx*gx; sgy2 += (double)gy*gy; sgz2 += (double)gz*gz;
    ok++; delay(5);
  }
  if (ok < N/2) return false;
  double mx = sax/ok, my = say/ok, mz = saz/ok;
  double mgx = sgx/ok, mgy = sgy/ok, mgz = sgz/ok;
  double gvar = (sgx2/ok - mgx*mgx) + (sgy2/ok - mgy*mgy) + (sgz2/ok - mgz*mgz);
  if (gvar > 4.0) { Serial.printf("calib REJECTED gvar=%.2f\n", gvar); return false; }
  rollOff  = atan2f((float)my, (float)mz) * 180.0f / PI;
  pitchOff = atan2f(-(float)mx, sqrtf((float)(my*my + mz*mz))) * 180.0f / PI;
  gxBias = mgx; gyBias = mgy; gzBias = mgz;
  Serial.printf("calib OK gvar=%.3f\n", gvar);
  return true;
}

static void onSent(const wifi_tx_info_t*, esp_now_send_status_t st) {
  if (st == ESP_NOW_SEND_SUCCESS) txOk++; else txFailCb++;
}

static bool initEspNow() {
  WiFi.mode(WIFI_STA);
  WiFi.disconnect();
  WiFi.setTxPower(TX_POWER);   // see TX_POWER note in USER CONFIG
  esp_wifi_set_ps(WIFI_PS_NONE);
  esp_wifi_set_channel(ESPNOW_CHANNEL, WIFI_SECOND_CHAN_NONE);
  if (esp_now_init() != ESP_OK) return false;
  esp_now_register_send_cb(onSent);
  esp_now_peer_info_t p = {};
  memcpy(p.peer_addr, BCAST_MAC, 6);
  p.channel = ESPNOW_CHANNEL;
  p.encrypt = false;
  return esp_now_add_peer(&p) == ESP_OK;
}

// Tear down and re-initialise the radio. Called after a run of consecutive
// esp_now_send failures (queue stuck / radio wedged), to self-heal without a
// full reset — mirrors the I2C bus-recovery pattern.
static void recoverEspNow() {
  esp_now_deinit();
  delay(2);
  initEspNow();
}

void setup() {
  Serial.begin(115200);
  delay(800);
  Serial.printf("\n[slave FINGER %u] booting (broadcast mode)\n", FINGER_ID);
  if (FINGER_ID == 3) {
    Serial.println("WARNING: FINGER_ID=3 is reserved for the master. Set 1, 2, 4, or 5.");
  }

  Wire.begin(SDA_PIN, SCL_PIN, I2C_HZ);
  Wire.setTimeOut(50);

  if (!configMpu()) { Serial.println("FATAL: I2C dead at boot"); while (1) delay(1000); }

  Serial.println("Calibrating, hold still...");
  while (!calibrateStill()) { delay(1000); }

  float ax,ay,az,gx,gy,gz;
  if (readImu(ax,ay,az,gx,gy,gz)) {
    kRoll.angle  = atan2f(ay, az) * 180.0f / PI - rollOff;
    kPitch.angle = atan2f(-ax, sqrtf(ay*ay + az*az)) * 180.0f / PI - pitchOff;
  }

  if (!initEspNow()) { Serial.println("FATAL: ESP-NOW init failed"); while (1) delay(1000); }
  Serial.print("Slave MAC: "); Serial.println(WiFi.macAddress());
  Serial.println("running — diagnostics every 5 s");
  delay((FINGER_ID - 1) * 6);   // phase stagger so 4 slaves don't collide
  lastUs = micros();
  nextUs = lastUs;
  windowStart = millis();
}

void loop() {
  // Deadline-scheduled 25 Hz
  unsigned long now = micros();
  if ((long)(now - nextUs) < 0) {
    long wait = (long)(nextUs - now);
    if (wait > 1500) delay((wait - 1000) / 1000);
    while ((long)(micros() - nextUs) < 0) { }
    now = micros();
  }
  nextUs += SEND_PERIOD_US;
  if ((long)(now - (nextUs + 2 * SEND_PERIOD_US)) > 0) nextUs = now + SEND_PERIOD_US;

  float ax,ay,az,gx,gy,gz;
  bool ok = readImu(ax,ay,az,gx,gy,gz);
  if (ok) { i2cOk++; }
  else    {
    i2cFail++;
    static uint32_t consecFail = 0;
    consecFail++;
    if (consecFail > 20) { recoverI2C(); consecFail = 0; }
    return;
  }

  float dt = (now - lastUs) / 1e6f;
  if (dt <= 0 || dt > 0.1f) dt = (float)SEND_PERIOD_US / 1e6f;
  lastUs = now;

  float gxC = gx - gxBias, gyC = gy - gyBias, gzC = gz - gzBias;
  float aMag = sqrtf(ax*ax + ay*ay + az*az);
  float devG = fabsf(aMag - G_TO_MS2);
  float gMag = sqrtf(gxC*gxC + gyC*gyC + gzC*gzC);
  bool isStill = (devG < STILL_ACC_MS2) && (gMag < STILL_GYRO_DPS);

  if (isStill) {
    gxBias += BIAS_EMA * (gx - gxBias);
    gyBias += BIAS_EMA * (gy - gyBias);
    gzBias += BIAS_EMA * (gz - gzBias);
    if (!stillFlag) { stillFlag = true; stillSince = millis(); }
  } else stillFlag = false;

  float gzd = (fabsf(gzC) < YAW_DEADBAND) ? 0.0f : gzC;
  yaw += gzd * dt;
  if (yaw >  YAW_MAX) yaw =  YAW_MAX;
  if (yaw < -YAW_MAX) yaw = -YAW_MAX;
  if (stillFlag && (millis() - stillSince) > STILL_RESET_MS) yaw = 0.0f;

  float accRoll  = atan2f(ay, az) * 180.0f / PI - rollOff;
  float accPitch = atan2f(-ax, sqrtf(ay*ay + az*az)) * 180.0f / PI - pitchOff;
  if (devG < ACCEL_GATE_MS2) {
    fPitch = kPitch.update(accPitch, gyC, dt);
    fRoll  = kRoll .update(accRoll,  gxC, dt);
  } else {
    fPitch = kPitch.predict(gyC, dt);
    fRoll  = kRoll .predict(gxC, dt);
  }

  pkt.finger_id = FINGER_ID;
  pkt.seq       = ++seq;
  pkt.t_ms      = millis();
  pkt.pitch = fPitch; pkt.roll = fRoll; pkt.yaw = yaw;
  pkt.gx = gxC; pkt.gy = gyC; pkt.gz = gzC;
  pkt.ax = ax;  pkt.ay = ay;  pkt.az = az;

  if (isfinite(pkt.pitch) && isfinite(pkt.roll) && isfinite(pkt.yaw)) {
    esp_err_t r = esp_now_send(BCAST_MAC, (uint8_t*)&pkt, sizeof(pkt));
    if (r != ESP_OK) {
      txFailImm++;
      // A run of failures means the radio TX path is wedged (queue full and
      // not draining). Re-init the radio to self-heal without a reset. No
      // per-event print — the count shows in the 5 s summary, so no log spam.
      if (++txConsecFail >= 25) {
        recoverEspNow();
        txConsecFail = 0;
      }
    } else {
      txConsecFail = 0;
    }
    // Single broadcast send (no dup, no ACK retries) — clean at 25 Hz.
  }

  // 5 s window summary
  if (millis() - windowStart >= 5000) {
    uint32_t reads = i2cOk + i2cFail;
    uint32_t sends = txOk + txFailCb + txFailImm;
    Serial.printf("[%lu] i2c=%lu/%lu(%.1f%% fail) tx ok=%lu cbFail=%lu immFail=%lu  P%+6.1f R%+6.1f Y%+6.1f\n",
                  (unsigned long)millis(),
                  (unsigned long)i2cFail, (unsigned long)reads,
                  reads ? (100.0f * i2cFail / reads) : 0.0f,
                  (unsigned long)txOk, (unsigned long)txFailCb, (unsigned long)txFailImm,
                  fPitch, fRoll, yaw);
    (void)sends;
    i2cOk = i2cFail = 0;
    txOk = txFailCb = txFailImm = 0;
    windowStart = millis();
  }
}

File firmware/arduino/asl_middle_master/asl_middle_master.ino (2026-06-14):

// ASL glove — middle-finger MASTER (XIAO ESP32-C3)
//
// DUAL-MODE. One compile flag selects the output path:
//
//   #define USE_BLE 1  -> BLE GATT notify to the phone (live inference)
//   #define USE_BLE 0  -> CSV over USB @ 921600 (feed scripts/record.py)
//
// Architecture (same in both modes):
//   - 4 slave XIAOs (thumb=1, index=2, ring=4, pinky=5) ESP-NOW unicast
//     FingerPackets to this master.
//   - Master reads its own MPU at 25 Hz (finger 3 = middle).
//   - Latest packet from each of the 5 fingers is latched.
//
// CSV mode: each packet is printed as a CSV line in record.py's column order.
// BLE mode: every 25 Hz cycle, the 5 latched fingers are packed into a
//           180-byte frame (45 little-endian float32) and pushed over a BLE
//           notify characteristic the Flutter app subscribes to.
//
// BLE payload channel order (must match record.py CSV / stats.json order):
//   finger 1 thumb : P R Y gx gy gz ax ay az   (bytes  0..35)
//   finger 2 index : P R Y gx gy gz ax ay az   (bytes 36..71)
//   finger 3 middle: P R Y gx gy gz ax ay az   (bytes 72..107)  <- own MPU
//   finger 4 ring  : P R Y gx gy gz ax ay az   (bytes 108..143)
//   finger 5 pinky : P R Y gx gy gz ax ay az   (bytes 144..179)
//
// BLE service: 12345678-1234-5678-1234-56789abcdef0
// BLE notify : 12345678-1234-5678-1234-56789abcdef1
// Device name: ASL-Glove
//
// Setup (BLE mode):
//   1. Set USE_BLE 1, flash to the middle XIAO.
//   2. Open Serial Monitor @ 115200, read the "BLE MAC: XX:.." line, paste it
//      into the app's lib/config/hardware_config.dart receiverMac, rebuild app.
//   3. Power the 4 slaves. Connect from the app.
//
// Setup (CSV mode):
//   1. Set USE_BLE 0, flash. Serial Monitor @ 921600.
//   2. Read "# Master MAC:" -> paste into asl_finger_slave MASTER_MAC.
//   3. Run scripts/record.py against the COM port.

#define USE_BLE 1   // <-- 1 = BLE to phone, 0 = CSV to record.py

#include <Arduino.h>
#include <WiFi.h>
#include <esp_now.h>
#include <esp_wifi.h>
#include <Wire.h>
#include <math.h>

#if USE_BLE
#include <BLEDevice.h>
#include <BLEServer.h>
#include <BLEUtils.h>
#include <BLE2902.h>
#define BLE_DEVICE_NAME  "ASL-Glove"
#define BLE_SERVICE_UUID "12345678-1234-5678-1234-56789abcdef0"
#define BLE_NOTIFY_UUID  "12345678-1234-5678-1234-56789abcdef1"
#endif

// ---- USER CONFIG ----------------------------------------------------------
static const uint8_t  MASTER_FINGER_ID = 3;
static const uint8_t  ESPNOW_CHANNEL   = 11;
static const uint32_t CYCLE_US         = 40000;   // 25 Hz
static const uint32_t STALE_MS         = 500;     // finger considered dropped
// --------------------------------------------------------------------------

static const int      SDA_PIN = 6;
static const int      SCL_PIN = 7;
static const uint32_t I2C_HZ  = 400000;

static const uint8_t MPU = 0x68;
static const uint8_t REG_SMPLRT_DIV  = 0x19;
static const uint8_t REG_CONFIG      = 0x1A;
static const uint8_t REG_GYRO_CONFIG = 0x1B;
static const uint8_t REG_ACCEL_CONFIG= 0x1C;
static const uint8_t REG_PWR_MGMT_1  = 0x6B;
static const uint8_t REG_WHO_AM_I    = 0x75;
static const uint8_t REG_ACCEL_XOUT  = 0x3B;
static const float ACCEL_LSB_PER_G  = 8192.0f;
static const float G_TO_MS2         = 9.80665f;
static const float GYRO_LSB_PER_DPS = 65.5f;

static const float    ACCEL_GATE_MS2 = 1.5f;
static const float    STILL_GYRO_DPS = 1.0f;
static const float    STILL_ACC_MS2  = 0.3f;
static const float    YAW_DEADBAND   = 5.0f;
static const float    YAW_MAX        = 180.0f;
static const uint32_t STILL_RESET_MS = 3000;
static const float    BIAS_EMA       = 0.005f;

typedef struct __attribute__((packed)) {
  uint8_t  finger_id;
  uint32_t seq;
  uint32_t t_ms;
  float    pitch, roll, yaw;
  float    gx, gy, gz;
  float    ax, ay, az;
} FingerPacket;

struct SourceState {
  uint32_t lastRxMs = 0;
  uint32_t rxCount  = 0;
  uint32_t lostCount= 0;
  uint32_t seq      = 0;
  FingerPacket pkt  = {};   // latest full packet, for BLE payload build
};
SourceState sources[6];                 // index 1..5
portMUX_TYPE srcLock = portMUX_INITIALIZER_UNLOCKED;

#if !USE_BLE
// CSV dedupe — only emit first copy of each (finger_id, seq) pair.
static uint32_t last_csv_seq[6] = {0};
#endif

// ---- Kalman (own MPU) ----
struct Kalman {
  float Q_angle = 0.001f, Q_bias = 0.003f, R_measure = 0.03f;
  float angle = 0.0f, bias = 0.0f;
  float P[2][2] = {{1,0},{0,1}};
  float predict(float rate, float dt) {
    float r = rate - bias;
    angle += dt * r;
    P[0][0] += dt * (dt*P[1][1] - P[0][1] - P[1][0] + Q_angle);
    P[0][1] -= dt * P[1][1];
    P[1][0] -= dt * P[1][1];
    P[1][1] += Q_bias * dt;
    return angle;
  }
  float update(float meas, float rate, float dt) {
    predict(rate, dt);
    float S = P[0][0] + R_measure;
    float K0 = P[0][0] / S, K1 = P[1][0] / S;
    float y = meas - angle;
    angle += K0 * y; bias += K1 * y;
    float P00 = P[0][0], P01 = P[0][1];
    P[0][0] -= K0 * P00; P[0][1] -= K0 * P01;
    P[1][0] -= K1 * P00; P[1][1] -= K1 * P01;
    return angle;
  }
};
Kalman mkPitch, mkRoll;
float mPitchOff = 0, mRollOff = 0;
float mGxBias = 0, mGyBias = 0, mGzBias = 0;
float mYaw = 0;
uint32_t mSeq = 0;
bool stillFlag = false;
uint32_t stillSince = 0;

#if USE_BLE
BLECharacteristic* gNotifyChar = nullptr;
volatile bool gBleConnected = false;
class ServerCallbacks : public BLEServerCallbacks {
  void onConnect(BLEServer*) override {
    gBleConnected = true;
    Serial.println("# [ble] client connected");
  }
  void onDisconnect(BLEServer* s) override {
    gBleConnected = false;
    Serial.println("# [ble] client disconnected — readvertising");
    s->startAdvertising();
  }
};
#endif

// ---- MPU helpers ----
static bool mpuWrite(uint8_t reg, uint8_t val) {
  Wire.beginTransmission(MPU); Wire.write(reg); Wire.write(val);
  return Wire.endTransmission() == 0;
}
static bool mpuRead(uint8_t reg, uint8_t* buf, size_t n) {
  Wire.beginTransmission(MPU); Wire.write(reg);
  if (Wire.endTransmission(false) != 0) return false;
  size_t got = Wire.requestFrom((int)MPU, (int)n, (int)true);
  if (got != n) return false;
  for (size_t i = 0; i < n; i++) buf[i] = Wire.read();
  return true;
}
static bool readImu(float& ax, float& ay, float& az,
                    float& gx, float& gy, float& gz) {
  uint8_t b[14];
  if (!mpuRead(REG_ACCEL_XOUT, b, 14)) return false;
  int16_t rax = (int16_t)((b[0]  << 8) | b[1]);
  int16_t ray = (int16_t)((b[2]  << 8) | b[3]);
  int16_t raz = (int16_t)((b[4]  << 8) | b[5]);
  int16_t rgx = (int16_t)((b[8]  << 8) | b[9]);
  int16_t rgy = (int16_t)((b[10] << 8) | b[11]);
  int16_t rgz = (int16_t)((b[12] << 8) | b[13]);
  ax = (rax / ACCEL_LSB_PER_G) * G_TO_MS2;
  ay = (ray / ACCEL_LSB_PER_G) * G_TO_MS2;
  az = (raz / ACCEL_LSB_PER_G) * G_TO_MS2;
  gx = rgx / GYRO_LSB_PER_DPS;
  gy = rgy / GYRO_LSB_PER_DPS;
  gz = rgz / GYRO_LSB_PER_DPS;
  return true;
}
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

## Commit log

2026-06-14 Initial commit: ASL Glove sign-language translation system
    Wearable five-finger IMU glove (XIAO ESP32-C3 + MPU6050 per finger) that
    recognises ASL gestures and speaks them, fully on-device.
    - firmware/arduino: master/slave ESP-NOW + BLE firmware, per-board diagnostics
    - flutter_app: Flutter app — BLE link, gated capture, on-device int8 1D-CNN, TTS
    - scripts: data recorder + relative-feature / augmentation / stats pipeline
    - raw datasets (letters, words), deployed models, KiCad hardware, LaTeX report
    [ASL_Glove-B_Cu.gbr, ASL_Glove-B_Mask.gbr, ASL_Glove-B_Paste.gbr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]
2026-06-14 Update per-board flash config toggles (FINGER_ID, USE_BLE, TX_POWER)
    Working build-state values set during bring-up; no behavioural code change.
2026-06-14 final ver
    [HOWAREYOU_001.csv, HOWAREYOU_002.csv, HOWAREYOU_003.csv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]
